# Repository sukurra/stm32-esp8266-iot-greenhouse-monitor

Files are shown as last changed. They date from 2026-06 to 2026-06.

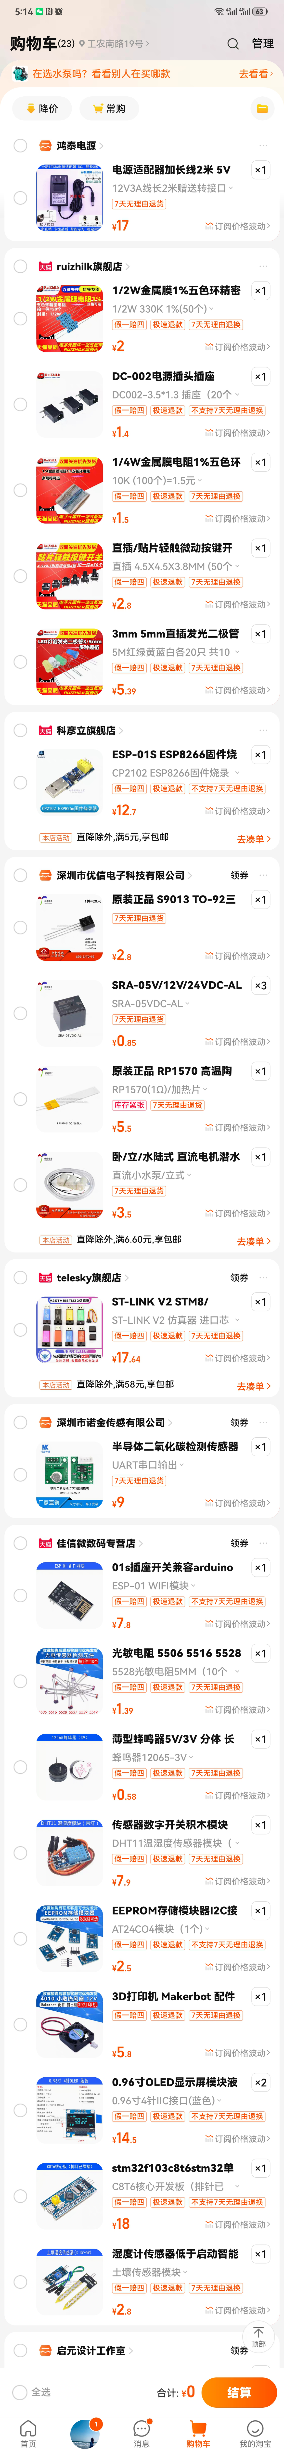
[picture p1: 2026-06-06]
元件清单.jpg

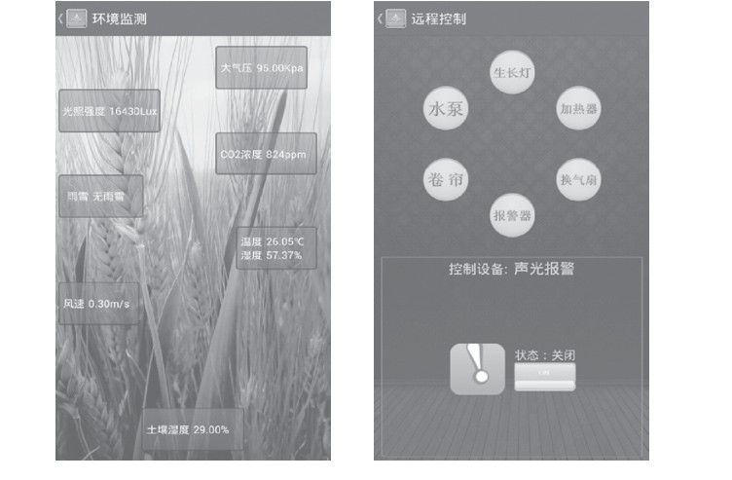
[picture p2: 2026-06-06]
文档图片/图片13.png

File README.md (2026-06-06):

# STM32 + ESP8266 物联网远程监控系统

> 一个面向农业大棚场景的嵌入式物联网远程监控项目，基于 STM32F103 实现环境数据采集、OLED 本地显示、执行器控制，并通过 ESP8266 接入机智云 APP 进行远程监测与控制。

本项目原型为农业大棚环境监测系统，适合作为嵌入式开发、物联网开发、单片机软硬件联调方向的求职展示项目。项目包含 STM32 固件源码、Keil 工程、传感器与执行器驱动、机智云通信协议、PCB/原理图、BOM、Proteus 仿真和项目文档资料。

建议 GitHub 仓库名：

```text
stm32-esp8266-iot-greenhouse-monitor
```

## 项目功能

- 环境数据采集：温湿度、CO2 浓度、土壤湿度、光照强度。
- 本地数据显示：通过 OLED 显示系统首页、环境数据、设备状态和功能菜单。
- 自动/手动控制：支持风扇、水泵、加热器、补光 LED、蜂鸣器等执行器控制。
- 远程监测控制：通过 ESP8266 接入机智云，实现 APP 端数据查看和设备控制。
- 阈值判断与状态提示：根据环境数据判断干旱、光照不足、CO2 状态等，并进行页面提示。
- 硬件资料配套：包含原理图、PCB、BOM、硬件接口说明和仿真工程。

## 技术栈

- 主控芯片：STM32F103
- 开发语言：C
- 开发环境：Keil uVision
- 通信模块：ESP8266
- 物联网平台：机智云 Gizwits
- 显示模块：OLED
- 传感器：DHT11、CO2 传感器、土壤湿度传感器、光敏电阻
- 执行器：风扇、水泵、加热器、补光 LED、蜂鸣器
- 仿真工具：Proteus
- 硬件设计：原理图、PCB、BOM

## 系统架构

```text
传感器层
  DHT11 / CO2 / 土壤湿度 / 光照强度
        |
        v
主控层
  STM32F103
  - ADC 采集
  - 串口通信
  - OLED 显示
  - 按键交互
  - 阈值判断
        |
        +--------------------+
        |                    |
        v                    v
执行器层                 云端/APP 层
风扇 / 水泵 / 加热器      ESP8266 + 机智云
补光 LED / 蜂鸣器         远程查看与控制
```

## 核心模块说明

| 模块 | 文件 | 说明 |
| --- | --- | --- |
| 主程序 | `代码/user/src/main.c` | 初始化外设并循环执行大棚监测主逻辑 |
| 页面显示 | `代码/user/src/show.c` | OLED 菜单、图标、环境数据和设备状态显示 |
| 温湿度采集 | `代码/user/src/dht11.c` | DHT11 温湿度数据读取 |
| CO2 采集 | `代码/user/src/co2.c` | CO2 浓度数据处理 |
| ADC 采集 | `代码/user/src/adc.c` | 土壤湿度、光照强度等模拟量采集 |
| 风扇控制 | `代码/user/src/fan.c` | 风扇开关控制 |
| 水泵控制 | `代码/user/src/water.c` | 灌溉水泵控制 |
| 加热控制 | `代码/user/src/hot.c` | 加热器控制 |
| 蜂鸣器 | `代码/user/src/buzzer.c` | 报警提示控制 |
| OLED 驱动 | `代码/user/src/oled.c` | OLED 底层显示驱动 |
| 按键输入 | `代码/user/src/key.c` | 本地按键扫描 |
| 机智云通信 | `代码/Gizwits/` | 数据点上报、APP 控制事件处理 |
| 工具模块 | `代码/Utils/` | 环形缓冲区、数据点处理等工具代码 |

## 硬件接口

| 外设 | 接口 |
| --- | --- |
| ESP8266 WiFi | PB11-RX，PB10-TX |
| OLED | PB12-SCK，PB13-SDA |
| DHT11 | PB14-DATA |
| CO2 传感器 | PA3 |
| 风扇 | PB15 |
| 光敏电阻 | PA5 |
| 补光 LED | PB0 |
| 水泵 | PA11 |
| 土壤湿度传感器 | PA4 |
| 蜂鸣器 | PB1 |
| 加热器 | PA7 |
| AT24C04 存储器 | PB7-SDA，PB6-SCL |
| 按键 | KEY1-PA0，KEY2-PB5，KEY3-PB8，KEY4-PB9 |

## 代码运行逻辑

系统上电后，`main.c` 依次初始化中断优先级、串口、LED、按键、OLED、DHT11、ADC、蜂鸣器、水泵、风扇、加热器、AT24C04、ESP8266 和机智云协议栈。

主循环中调用 `Smart_Greenhouse()` 执行大棚监测逻辑，并在功能页面中通过 `Wifi_date()` 调用机智云协议处理函数，实现数据上报与 APP 控制指令接收。

机智云数据点主要包括：

- `Temp`：温度
- `Humi`：湿度
- `CO2`：二氧化碳浓度
- `Light`：光照强度
- `Soil`：土壤湿度
- `Water`：水泵开关
- `Fan`：风扇开关
- `LED`：补光 LED 档位
- `Voice`：蜂鸣器开关
- `All`：一键控制

## 编译与烧录

1. 使用 Keil uVision 打开工程文件：

   ```text
   代码/project/smart-greenhouse.uvprojx
   ```

2. 在 `代码/Gizwits/gizwits_protocol.h` 中填入自己的机智云产品参数：

   ```c
   #define PRODUCT_KEY "YOUR_GIZWITS_PRODUCT_KEY"
   #define PRODUCT_SECRET "YOUR_GIZWITS_PRODUCT_SECRET"
   ```

   公开仓库中不包含真实 Product Key 和 Product Secret。

3. 确认目标芯片为 STM32F103 系列。

4. 编译工程，生成固件。

5. 通过 ST-Link 或其他下载器将程序烧录到 STM32 开发板。

6. ESP8266 固件可参考目录：

   ```text
   ESP8266固件烧录/
   ```

7. APP 安装包和说明位于：

   ```text
   机智云APP/
   ```

## 仿真与硬件资料

| 类型 | 路径 |
| --- | --- |
| Proteus 仿真工程 | `仿真/stm32f103.pdsprj` |
| 仿真/烧录 hex | `仿真/smart-greenhouse.hex` |
| 原理图 PDF | `PCB/原理图.pdf` |
| 核心电路板 PDF | `PCB/核心电路板.pdf` |
| PCB 文件 | `PCB/PCB(改版20231122）.PcbDoc` |
| BOM | `bom.xlsx` |
| 硬件接口说明 | `毕设硬件对接口.txt` |

## 项目目录

当前资料包目录如下：

```text
农业大棚环境监测系统全资料/
├─ 代码/                 STM32 固件源码、Keil 工程、CMSIS、外设库
├─ PCB/                  原理图、PCB、BOM 导出文件、历史版本
├─ 仿真/                 Proteus 仿真工程和 hex 文件
├─ ESP8266固件烧录/       ESP8266 固件和烧录工具
├─ 机智云APP/             Android/iOS APP 安装包和说明
├─ 文档图片/              项目图片、页面图、硬件图等
├─ 讲解视频/              项目讲解视频
├─ bom.xlsx              元件清单
└─ 相关论文/PPT/文档       毕设论文、答辩 PPT、参考资料
```

如果用于 GitHub 求职展示，建议整理为：

```text
smart-greenhouse-monitor/
├─ README.md
├─ LICENSE
├─ .gitignore
├─ firmware/             STM32 固件源码和 Keil 工程
├─ hardware/             原理图、PCB、BOM、接口说明
├─ simulation/           Proteus 仿真工程
├─ docs/                 项目说明、架构图、运行截图
└─ app/                  机智云 APP 使用说明
```

## 个人贡献

- 完成 STM32 主控程序设计与外设初始化。
- 编写温湿度、CO2、土壤湿度、光照强度等数据采集模块。
- 实现 OLED 菜单页面、图标显示和状态展示。
- 实现风扇、水泵、加热器、补光 LED、蜂鸣器等执行器控制。
- 对接 ESP8266 与机智云平台，实现数据点上报和 APP 远程控制。
- 整理硬件接口、原理图、PCB、BOM 和仿真资料，完成软硬件联调。

## 项目亮点

- 软硬件资料完整：源码、工程、仿真、原理图、PCB、BOM 均有配套。
- 模块化代码结构：传感器、显示、通信、执行器控制分模块实现，便于维护和扩展。
- 具备物联网闭环：本地采集、本地显示、本地控制、云端上报、APP 控制流程完整。
- 贴近真实农业场景：围绕温湿度、土壤湿度、光照和 CO2 等关键环境参数进行监测与控制。

## 后续优化方向

- 增加更多传感器，如光照数字传感器、土壤温度、PH 值等。
- 增加历史数据存储和曲线展示。
- 优化自动控制策略，支持多级阈值和定时控制。
- 增加异常报警策略，如传感器离线、通信断开、执行器故障等。
- 将 APP 端数据展示和控制逻辑进一步产品化。

## 说明

本仓库为毕业设计和求职展示项目，重点展示嵌入式系统开发、传感器采集、执行器控制、物联网通信和硬件联调能力。

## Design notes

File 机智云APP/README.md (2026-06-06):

# 机智云 APP 使用说明

本项目通过 ESP8266 接入机智云平台，用于在手机端查看农业大棚环境数据并远程控制设备。

## 支持功能

- 查看温度、湿度、CO2 浓度、光照强度、土壤湿度等数据。
- 远程控制水泵、风扇、蜂鸣器和补光 LED。
- 支持一键控制相关执行器。

## 使用说明

1. 给 STM32 主控板和 ESP8266 模块上电。
2. 根据机智云配网流程，将 ESP8266 连接到可用 WiFi。
3. 在 APP 中绑定设备。
4. 进入设备页面查看实时数据，并测试水泵、风扇、LED 等远程控制功能。

## 注意

原始资料包中包含 Android 和 iOS 安装包。为了避免 GitHub 仓库过大，当前求职展示仓库不上传 `apk` 和 `ipa` 文件，只保留使用说明。

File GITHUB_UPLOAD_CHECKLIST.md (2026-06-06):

# GitHub 上传前整理清单

本清单用于把当前毕业设计资料包整理成适合求职展示的 GitHub 仓库。

## 仓库信息

- 推荐仓库名：`stm32-esp8266-iot-greenhouse-monitor`
- 推荐项目标题：`STM32 + ESP8266 物联网远程监控系统`
- 推荐描述：`基于 STM32F103 和 ESP8266 的农业大棚环境监测与远程控制系统，支持环境采集、OLED 显示、执行器控制和机智云 APP 远程监控。`
- 推荐标签：`stm32`、`esp8266`、`iot`、`embedded-c`、`greenhouse`、`gizwits`、`keil`

## 建议上传

- `README.md`
- `.gitignore`
- `代码/user/`
- `代码/Gizwits/`
- `代码/Utils/`
- `代码/CMSIS/`
- `代码/lib/`
- `代码/project/smart-greenhouse.uvprojx`
- `PCB/原理图.pdf`
- `PCB/核心电路板.pdf`
- `PCB/PCB(改版20231122）.PcbDoc`
- `仿真/stm32f103.pdsprj`
- `bom.xlsx`
- `毕设硬件对接口.txt`
- 精选后的 `文档图片/`

## 不建议上传

- Keil 编译产物：`Objects/`、`Listings/`、`*.o`、`*.d`、`*.crf`、`*.axf`、`*.map`
- 用户本地配置：`*.uvguix.*`
- 大视频和大 PPT：`讲解视频/`、`答辩PPT.pptx`
- 参考资料和格式模板：参考论文、论文格式 PDF、无关项目 PPT
- 第三方工具和安装包：`*.exe`、`*.apk`、`*.ipa`
- 可能包含个人信息的论文、答辩材料、班级姓名文件

## 上传后检查

- GitHub 首页能直接看到 README 内容。
- README 第一屏能说明项目是什么、用了什么技术、能做什么。
- 仓库体积不要过大，尽量控制在几十 MB 内。
- 仓库文件名尽量清楚，避免出现大量临时文件、编译产物和历史版本。
- 至少放 3 张项目图：硬件实物图、OLED/APP 效果图、系统架构图或 PCB 图。

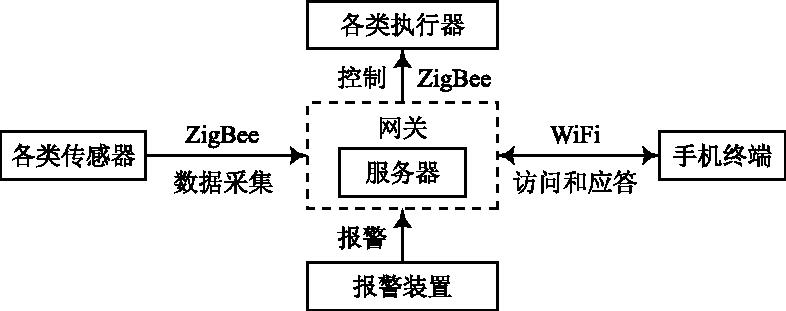
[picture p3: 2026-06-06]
文档图片/图片1.png

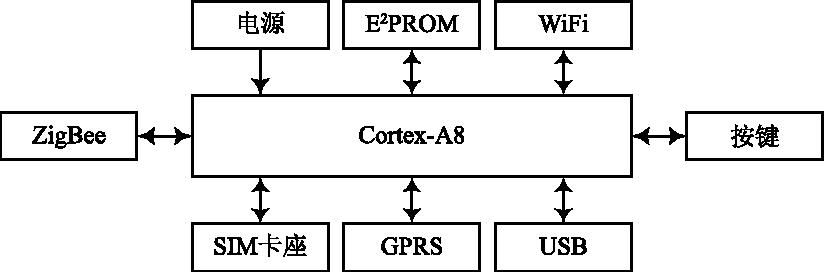
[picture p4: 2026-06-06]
文档图片/图片2.png

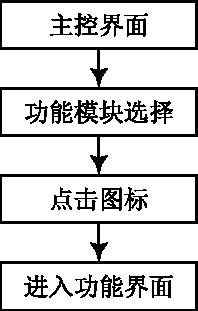
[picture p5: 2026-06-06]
文档图片/图片11.png

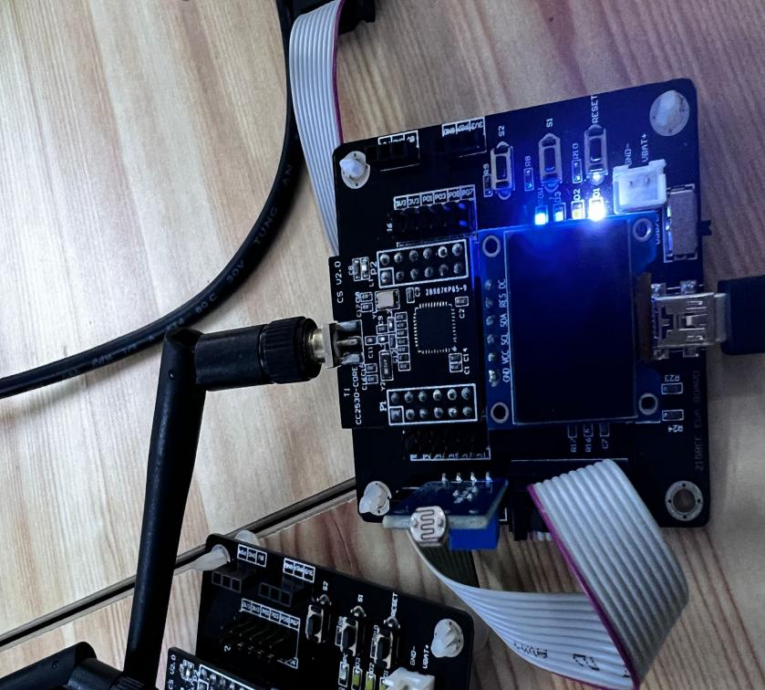
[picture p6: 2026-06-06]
文档图片/图片3.png

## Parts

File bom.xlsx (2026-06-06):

元器件清单
元器件型号 | 元器件名称 | 数量
温湿度传感器 | dht11 | 1
电源插座 | dc-3.5*1.3 | 1
WiFi模块 | esp8266 | 1
显示屏 | 四针0.96寸oled | 1
stm32f103c8t6 | 最小系统板 | 1
记忆模块 | AT24CO4 | 1
二氧化碳模块 | JW01 | 1
继电器 | SRA-05VDC | 3
加热片 | RP1570 | 1
风扇 | 风扇 | 1
水泵 | 直流水泵 | 1
10k电阻 | 直插 | 1
330Ω电阻 | 直插 | 5
光敏电阻 | 5528直插 | 1
三极管 | S9013 TO-92 | 4
发光二极管 | 5M直插 | 1
按键 | 直插 4.5*4.5*3.8MM | 4
电源插座 | 12V3A 3.5*1.3 | 1
蜂鸣器 | 3v有源蜂鸣器 | 1

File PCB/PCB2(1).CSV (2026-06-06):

Bill of Material for
On 2023/8/24 at 22:47:47
Comment | Pattern | Quantity | Components
10K | AXIAL0.3 | 1 | R5 | 电阻
330R | AXIAL0.3 | 4 | R1, R2, R3, R6 | 电阻
330欧 | AXIAL0.3 | 1 | R7 | 电阻
5V4相 | SIP5 | 1 | DJ1
BELL | bell | 1 | b1
CK | ESP-01S | 1 | 3
CON4 | JW01 | 1 | J2
CON4 | SIP4 | 1 | J3
CON5 | SIP5 | 1 | BH1
CON6 | SIP6 | 1 | J1
DC | DC3.5-1.3 | 1 | D1
DHT11 | DHT11 | 1 | U1
DS18B20 | DS18B20 | 1 | DS1
NB | M5310A | 1 | 4
NPN | S9013 | 4 | Q1, Q2, Q3, Q4
OLED屏幕 | OLED | 1 | 4
SD | SIP4 | 2 | SD1, SD2
SGP30 | SGP30 | 1 | M1
ULN2003 | ULN2003 | 1 | ULN1
干电池 | BT | 1 | BT1
光敏电阻 | GM_R | 1 | R4 | Battery
核心板 | C8T6核心板 | 1 | C1
继电器 | 5继电器 | 3 | JDQ1, JDQ2, JDQ3
排扇 | SIP2 | 1 | 1
水泵 | SIP2 | 2 | 2, 5

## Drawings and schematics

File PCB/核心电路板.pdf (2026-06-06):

核心板电路 | GND
| VCC3.3PB¹² PB¹³

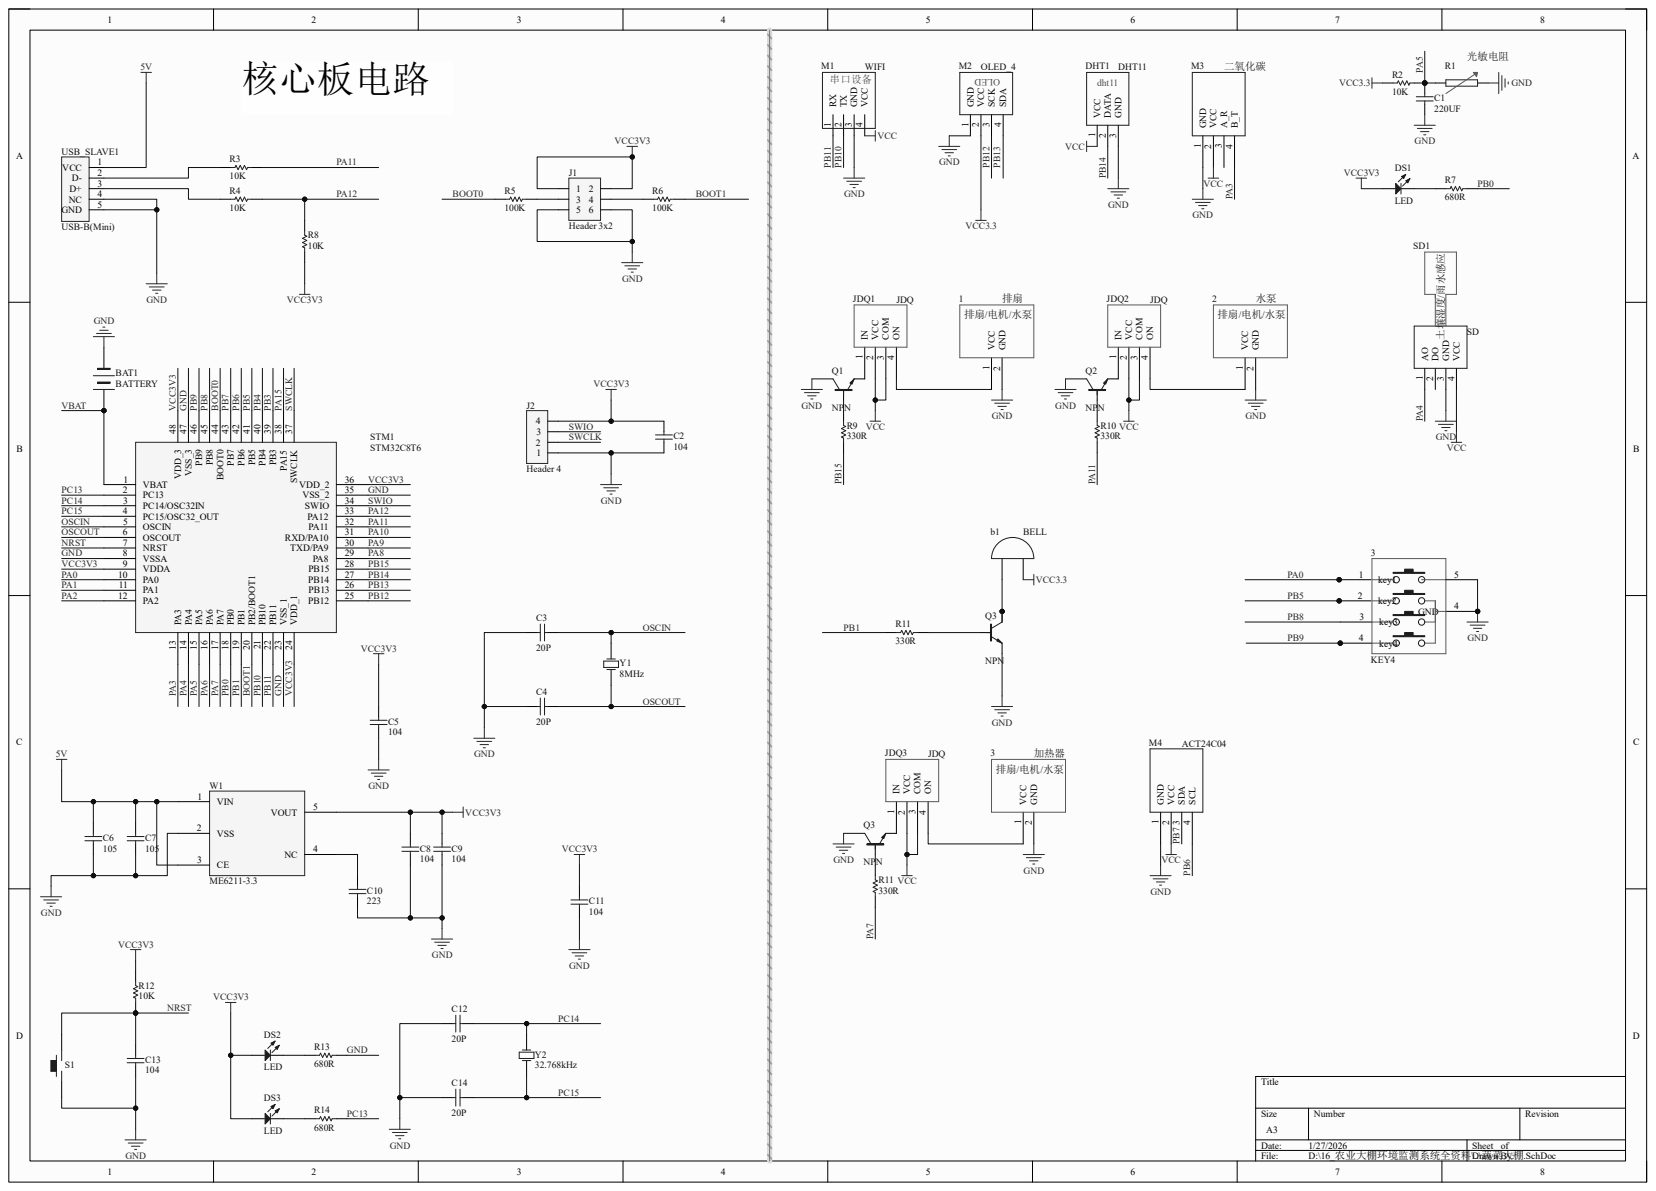
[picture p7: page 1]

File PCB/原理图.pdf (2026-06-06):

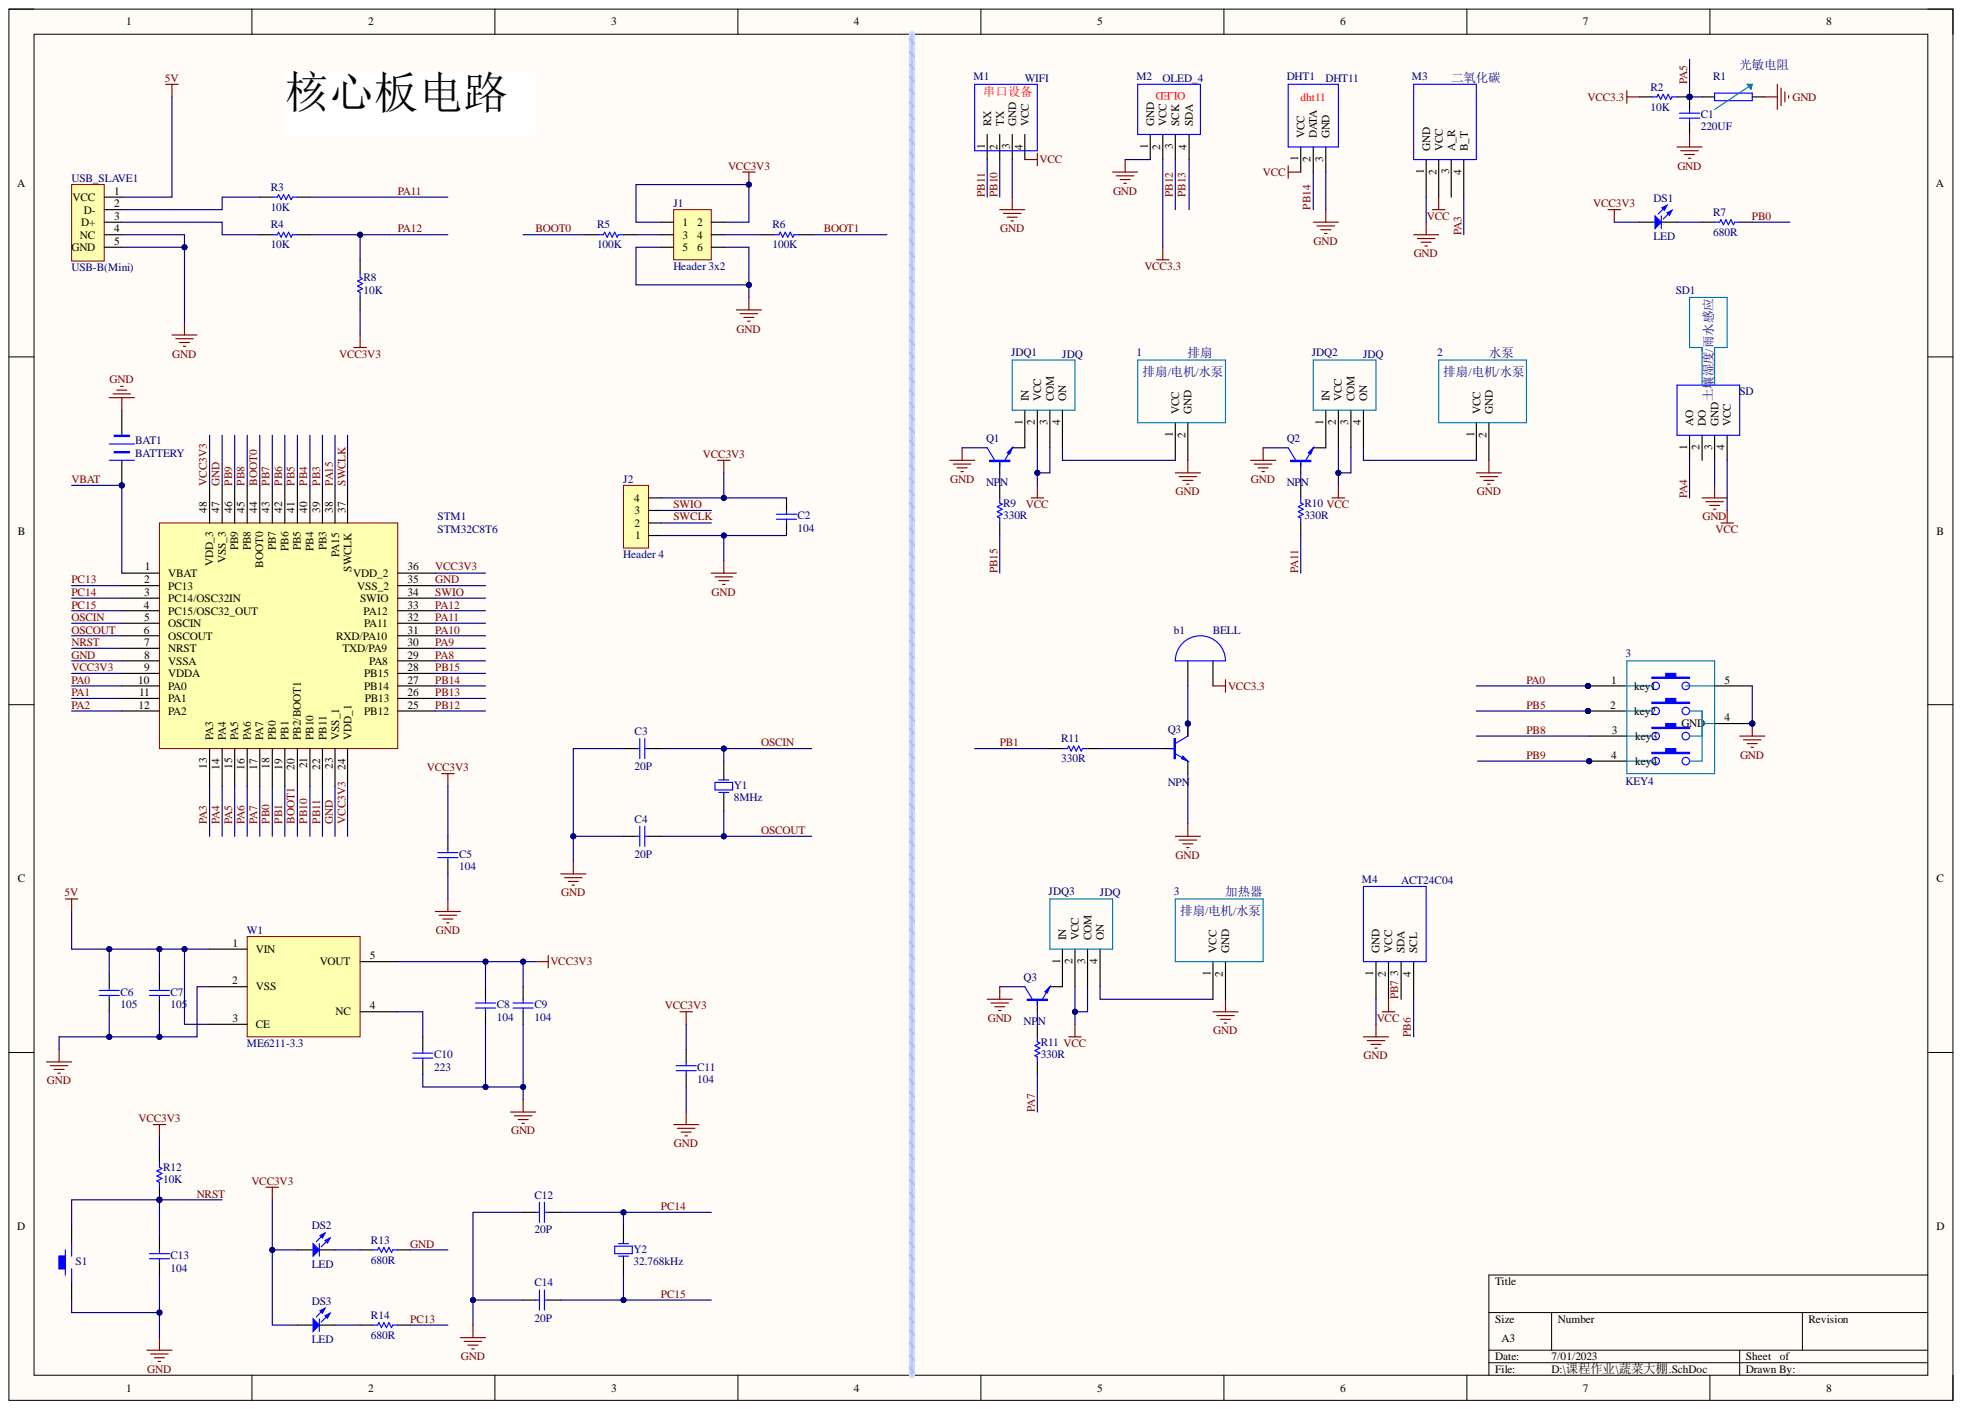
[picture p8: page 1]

VSS 2

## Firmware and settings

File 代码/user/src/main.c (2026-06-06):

#include "gizwits_product.h"
#include "gizwits_protocol.h"
#include "main.h"
extern dataPoint_t currentDataPoint;
 void Gizwits_Init(void)
{
	Tim1_Init();//TIM1初始化
	Usart3_Init(9600);//USART3+初始化
	memset((uint8_t*)&currentDataPoint, 0, sizeof(dataPoint_t));
	gizwitsInit();
}
int main(void)
{

	NVIC_PriorityGroupConfig(NVIC_PriorityGroup_2);//中断组的选择
	Usart1_Init(115200);//串口1初始化
	Led_Init();//LED补光初始化
  Key_Init();//按键初始化
	OLED_Init();//OLED初始化
	DHT11_Init();//DHT11初始化
	ADC1_Init();//模数转换初始化。土壤、光照强度转换
	Buz_Init();//蜂鸣器初始化
	Water_Init();//水泵初始化
	Fan_Init();//风扇初始化
	Hot_Init();//加热器初始化
	Act24_Init();//数据存储器初始化
	usart2_init(9600);
	Gizwits_Init();//机智云初始化

	printf("初始化成功\r\n");
//	Pass_lock();
//	u8 rec0[5];
//	static	u8 temp=0;//放置存储器中的密码
//	Act24_ContinueRead(&temp,21,sizeof(temp),6);//读密码区间数据
//	sprintf((char *)rec0,"%d℃",temp);
//	Oled_ShowAll(0,80,rec0);//显示中英字符串
//	Oled_ShowAll(2,80,"123");//显示中英字符串
//	Hot_ON;
while(1)
{

	
	
//	key = key_scan();
//		if(key == 1)//设置配网模式
//		{
//			printf("sss\r\n");
//			gizwitsSetMode(WIFI_AIRLINK_MODE);//手机广播配网
//			printf("WIFI_AIRLINK_MODE OK\r\n");
//		}
//		if(key == 2)//恢复出厂设置
//		{
//			printf("aaa\r\n");
//			gizwitsSetMode(WIFI_RESET_MODE);//恢复出厂设置
//			printf("WIFI_RESET_MODE OK\r\n");
//		}
//		
//	gizwitsHandle(&currentDataPoint);//上报函数
//	userHandle();//数据上传

Smart_Greenhouse();


}







}

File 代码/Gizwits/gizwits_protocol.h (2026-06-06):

/**
************************************************************
* @file         gizwits_protocol.h
* @brief        Corresponding gizwits_product.c header file (including product hardware and software version definition)
* @author       Gizwits
* @date         2017-07-19
* @version      V03030000
* @copyright    Gizwits
* 
* @note         机智云.只为智能硬件而生
*               Gizwits Smart Cloud  for Smart Products
*               链接|增值ֵ|开放|中立|安全|自有|自由|生态
*               www.gizwits.com
*
***********************************************************/

#ifndef _GIZWITS_PROTOCOL_H
#define _GIZWITS_PROTOCOL_H

#ifdef __cplusplus
extern "C" {
#endif

#include <stdint.h>
#include <stdbool.h>
#include <stdio.h>
#include <stdlib.h>
#include <string.h>
#include "common.h"

                                                                                                                  
#define SEND_MAX_TIME       200                     ///< 200ms resend
#define SEND_MAX_NUM        2                       ///< resend times
                                                    
#define protocol_VERSION    "00000004"              ///< protocol version
#define P0_VERSION          "00000002"              ///< P0 protocol version

/**@name Product Key  
* @{
*/
#define PRODUCT_KEY "YOUR_GIZWITS_PRODUCT_KEY"
/**@} */
/**@name Product Secret  
* @{
*/
#define PRODUCT_SECRET "YOUR_GIZWITS_PRODUCT_SECRET"
               
/**@name Device status data reporting interval
* @{
*/
#define REPORT_TIME_MAX 6000 //6S
/**@} */    

#define CELLNUMMAX 7    


/**@name Whether the device is in the control class, 0 means no, 1 means yes
* @{
*/
#define DEV_IS_GATEWAY   0//中控设备   
#define DEV_IS_GATEWAY2  0//网关设备      
/**@} */

/**@name Binding time
* @{
*/
#define NINABLETIME  0
/**@} */



#define MAX_PACKAGE_LEN    (sizeof(devStatus_t)+sizeof(attrFlags_t)+20)                 ///< Data buffer maximum length
#define RB_MAX_LEN          (MAX_PACKAGE_LEN*2)     ///< Maximum length of ring buffer

/**@name Data point related definition
* @{
*/
#define Water_BYTEOFFSET                    0
#define Water_BITOFFSET                     0
#define Water_LEN                           1
#define Fan_BYTEOFFSET                    0
#define Fan_BITOFFSET                     1
#define Fan_LEN                           1
#define All_BYTEOFFSET                    0
#define All_BITOFFSET                     2
#define All_LEN                           1
#define Voice_BYTEOFFSET                    0
#define Voice_BITOFFSET                     3
#define Voice_LEN                           1
#define LED_BYTEOFFSET                    0
#define LED_BITOFFSET                     4
#define LED_LEN                           2

#define Temp_RATIO                         1
#define Temp_ADDITION                      0
#define Temp_MIN                           0
#define Temp_MAX                           55
#define Humi_RATIO                         1
#define Humi_ADDITION                      5
#define Humi_MIN                           0
#define Humi_MAX                           90
#define CO2_RATIO                         1
#define CO2_ADDITION                      0
#define CO2_MIN                           0
#define CO2_MAX                           100
#define Light_RATIO                         1
#define Light_ADDITION                      0
#define Light_MIN                           0
#define Light_MAX                           100
#define Soil_RATIO                         1
#define Soil_ADDITION                      0
#define Soil_MIN                           0
#define Soil_MAX                           100
/**@} */

/** Writable data points Boolean and enumerated variables occupy byte size */
#define COUNT_W_BIT 1






typedef enum
{
    LED_VALUE0 = 0,//低
    LED_VALUE1 = 1,//中
    LED_VALUE2 = 2,//强
    LED_VALUE3 = 3,//关闭
    LED_VALUE_MAX,
} LED_ENUM_T;

/** Event enumeration */
typedef enum
{
    WIFI_SOFTAP = 0x00,                               ///< WiFi SOFTAP configuration event
    WIFI_AIRLINK,                                     ///< WiFi module AIRLINK configuration event
    WIFI_STATION,                                     ///< WiFi module STATION configuration event
    WIFI_OPEN_BINDING,                                ///< The WiFi module opens the binding event
    WIFI_CLOSE_BINDING,                               ///< The WiFi module closes the binding event
    WIFI_CON_ROUTER,                                  ///< The WiFi module is connected to a routing event
    WIFI_DISCON_ROUTER,                               ///< The WiFi module has been disconnected from the routing event
    WIFI_CON_M2M,                                     ///< The WiFi module has a server M2M event
    WIFI_DISCON_M2M,                                  ///< The WiFi module has been disconnected from the server M2M event
    WIFI_OPEN_TESTMODE,                               ///< The WiFi module turns on the test mode event
    WIFI_CLOSE_TESTMODE,                              ///< The WiFi module turns off the test mode event
    WIFI_CON_APP,                                     ///< The WiFi module connects to the APP event
    WIFI_DISCON_APP,                                  ///< The WiFi module disconnects the APP event
    WIFI_RSSI,                                        ///< WiFi module RSSI event
    WIFI_NTP,                                         ///< Network time event
    MODULE_INFO,                                      ///< Module information event
    TRANSPARENT_DATA,                                 ///< Transparency events
    EVENT_Water,
    EVENT_Fan,
    EVENT_All,
    EVENT_Voice,
    EVENT_LED,
    EVENT_TYPE_MAX                                    ///< Enumerate the number of members to calculate (user accidentally deleted)
} EVENT_TYPE_T;

/** P0 Command code */
typedef enum
{
    ACTION_CONTROL_DEVICE       = 0x01,             ///< Protocol 4.10 WiFi Module Control Device WiFi Module Send
    ACTION_READ_DEV_STATUS      = 0x02,             ///< Protocol 4.8 WiFi Module Reads the current status of the device WiFi module sent
    ACTION_READ_DEV_STATUS_ACK  = 0x03,             ///< Protocol 4.8 WiFi Module Read Device Current Status Device MCU Reply
    ACTION_REPORT_DEV_STATUS    = 0x04,             ///< Protocol 4.9 device MCU to the WiFi module to actively report the current status of the device to send the MCU
    ACTION_W2D_TRANSPARENT_DATA = 0x05,             ///< WiFi to device MCU transparent
    ACTION_D2W_TRANSPARENT_DATA = 0x06,             ///< Device MCU to WiFi
} actionType_t;   

/** Protocol network time structure */
typedef struct
{
    uint16_t year;
    uint8_t month;
    uint8_t day;
    uint8_t hour;
    uint8_t minute;
    uint8_t second;
    uint32_t ntp;
}protocolTime_t;
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
